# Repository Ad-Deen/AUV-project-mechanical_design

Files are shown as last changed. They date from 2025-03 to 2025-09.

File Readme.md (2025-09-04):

# AUV Mechanical Design - Evolution & Strategy

## Overview
This repository documents the mechanical design considerations and evolution of our Autonomous Underwater Vehicle (AUV) Project - Orca. The primary focus is on achieving optimal buoyancy, stability, and structural integrity while ensuring efficiency in underwater maneuverability.



## **Version 1: Initial Design & Challenges**

### **Design Approach:**
- The **center of mass** was initially intended to be at the geometric center of the bot.
- An **aluminum frame** was used to hold the hull, providing structural support.
- The frame was **hollow**, which contributed to **positive buoyancy**.

### **Manufactured results:**

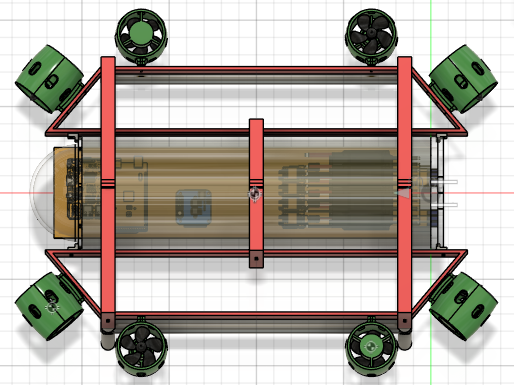
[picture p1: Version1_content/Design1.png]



### **Challenges Faced:**
- The **center of mass** shifted backward, affecting stability.
- The **bot became overly buoyant**, requiring **up to 15 kg** of additional external weight to counteract the buoyancy.
- Excessive weight led to:
  - **High inertia**, making rapid underwater maneuvers difficult.
  - **Increased battery consumption** due to the excessive mass to be controlled.
- The overall design proved inefficient in terms of weight distribution and control underwater.

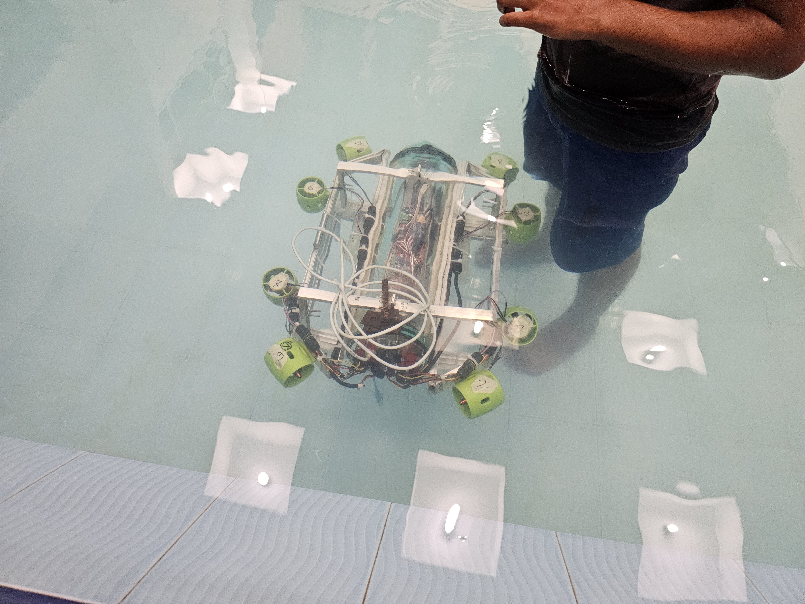
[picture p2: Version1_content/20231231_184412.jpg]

- The natural bouyancy control mechanism was also made but not utilized for core design issues
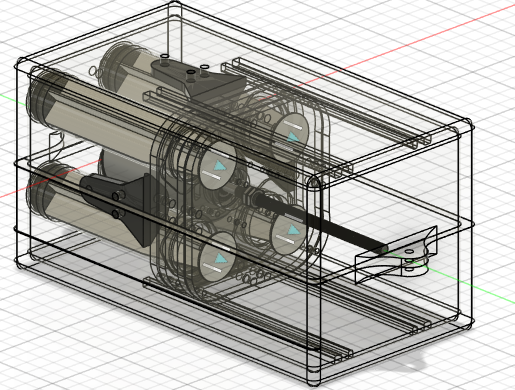
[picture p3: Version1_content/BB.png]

-The Buoyancy control mechanism in action 



## **Version 2: Optimized Design & Improvements**
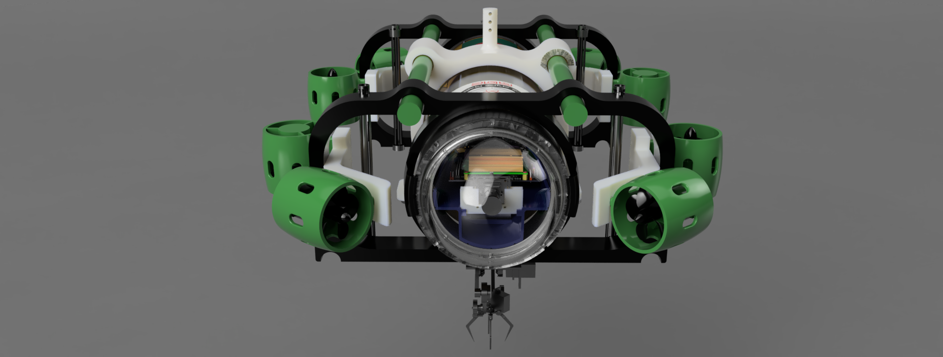
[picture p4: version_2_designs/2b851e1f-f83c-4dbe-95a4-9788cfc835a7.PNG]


### **Design Modifications:**
- The frame was **redesigned and 3D printed** with **100% infill density wiht PETG** to achieve a **negatively buoyant** structure.
- External volume was **minimized**, reducing drag and making the design more compact.
- The updated frame, in combination with:
  - The **weight of electronics**
  - **External weight holders**
  ensured the bot achieved **neutral buoyancy at 9 kg**, without requiring additional weights.
- Slots were still included in the design for **optional weight adjustments**, providing flexibility.

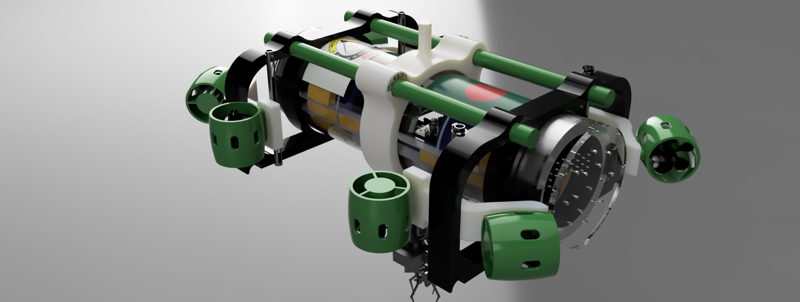
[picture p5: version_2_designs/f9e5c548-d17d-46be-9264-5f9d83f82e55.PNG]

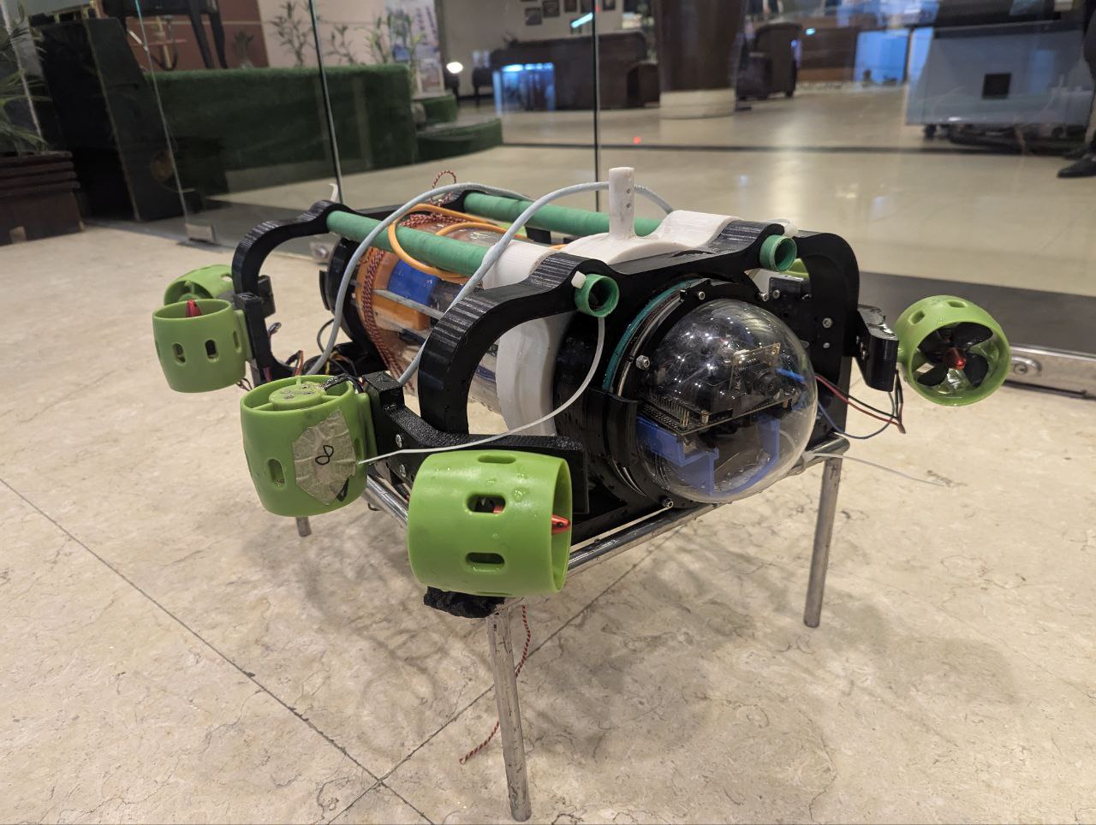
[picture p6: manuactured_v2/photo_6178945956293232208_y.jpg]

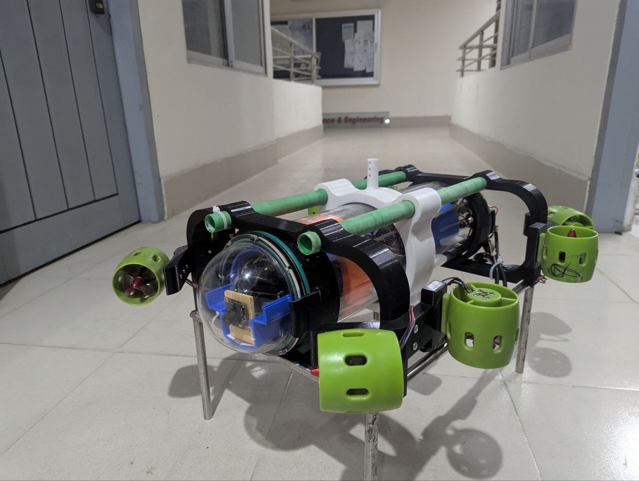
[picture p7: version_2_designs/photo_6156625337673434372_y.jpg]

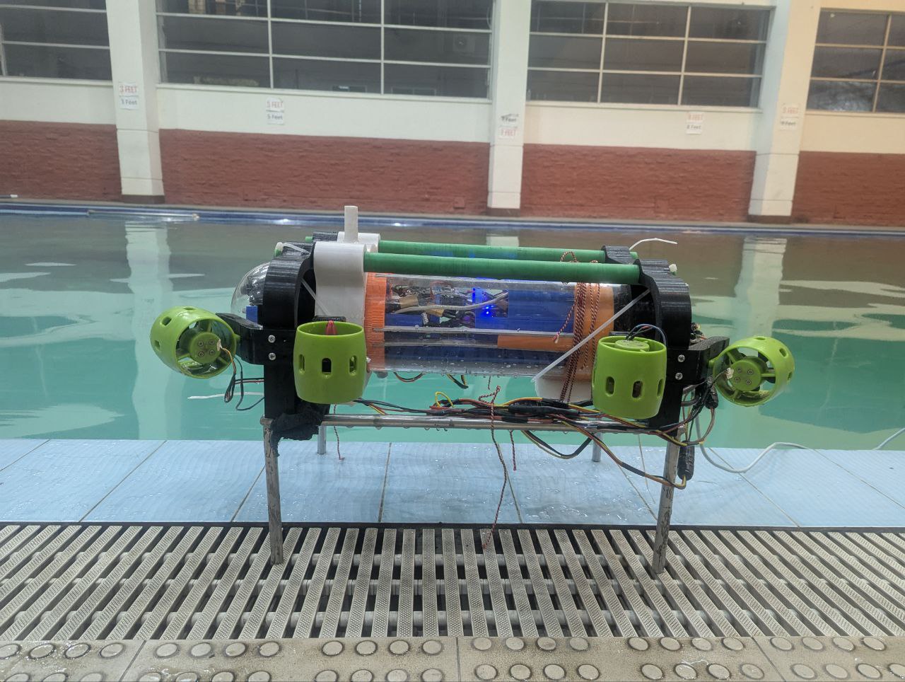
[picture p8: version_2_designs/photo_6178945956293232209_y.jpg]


### **Centre of Gravity adjustment system:**
- **The x axis is th principal axis for the robot's orientation** and we can adjust centre of gravity distribution along the principal axis for **robust passive adjustment** of it's centre of gravity alighment.
- The design was done in such a way that the center of gravity must lie along the central **x-axis**.
- While **variable adjustment of CoG along x axis** means we can accurately maintain a steady Centre of gravity position at **pitch close to 0 degree**.
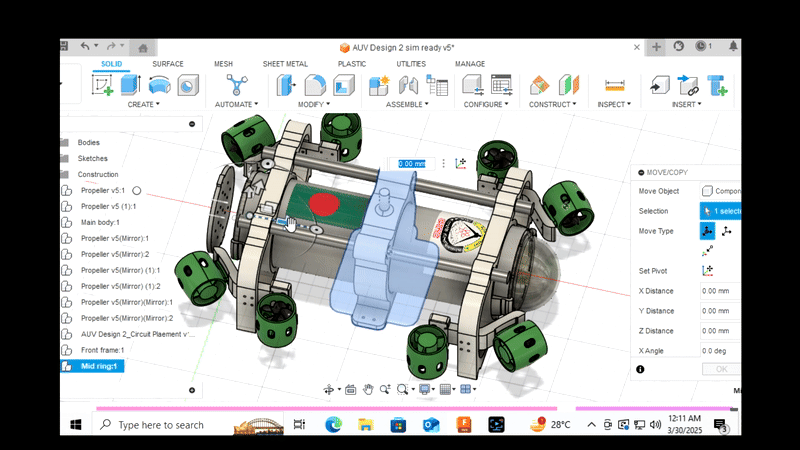
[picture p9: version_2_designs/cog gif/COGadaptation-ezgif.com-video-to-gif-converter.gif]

- Here is the working version of the same mechanism on our AUV


### **Internal Design for Electronics assembly:**
- Hull internal chamber is designed to accomodate the power and logic circuit with esc controllers and micro controllers.
- The 3D prints are done with PETG+ 100% infill density.
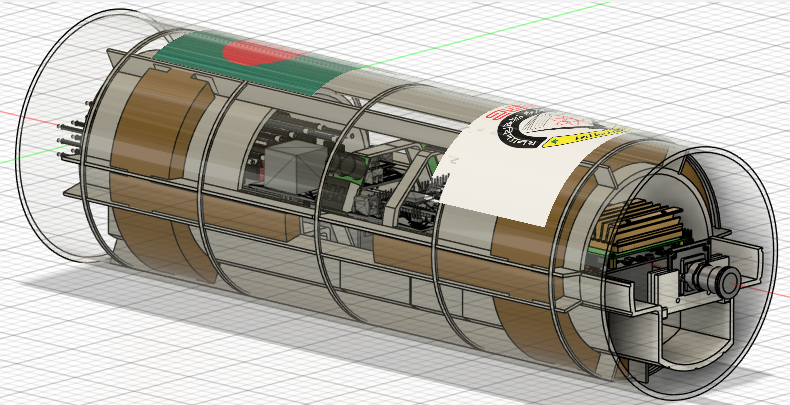
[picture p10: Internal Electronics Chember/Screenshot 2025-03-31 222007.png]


<div style="white-space: nowrap;">
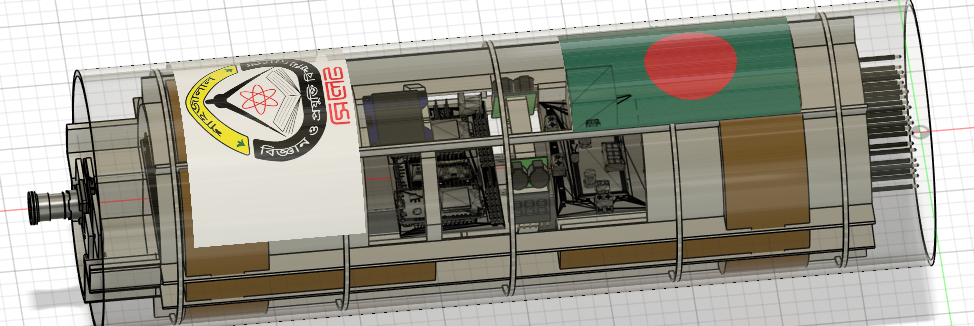
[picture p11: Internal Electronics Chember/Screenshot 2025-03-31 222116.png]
  
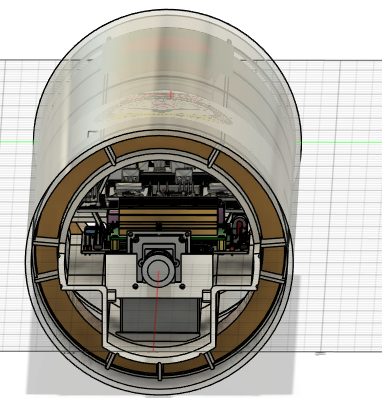
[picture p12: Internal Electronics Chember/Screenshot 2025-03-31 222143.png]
  
</div>
- The internal design section placed with electronics after the manufacturing and printing the Designs

   

### **Custom 6 DOF manipulator Design:**
- One of the **primary task** was to **pick up a 3cm radius ball** from a busket underwater.
- So we designed a robotic manipulator for it. The **launch pad consist of a camera**. The base (the launching pad) has a **radial targeting system with 2 underwater servo for Azimuth and Elevation adjustment**.
- Another servo to **launch the gripper to the target**. ANother **string based controlled gripper** with a mini servo to grip the target.
- This ensures smooth targeting and launching of the End Effector towards the target calculating underwater proximity using the camera.
- The **bavel gear system allowed opposite rotary mechanism** to launch the EF to the target with accurate mechanism **avoiding the need for and addition servo for two extension rods holding the EF**.
  
<div style="white-space: nowrap;">
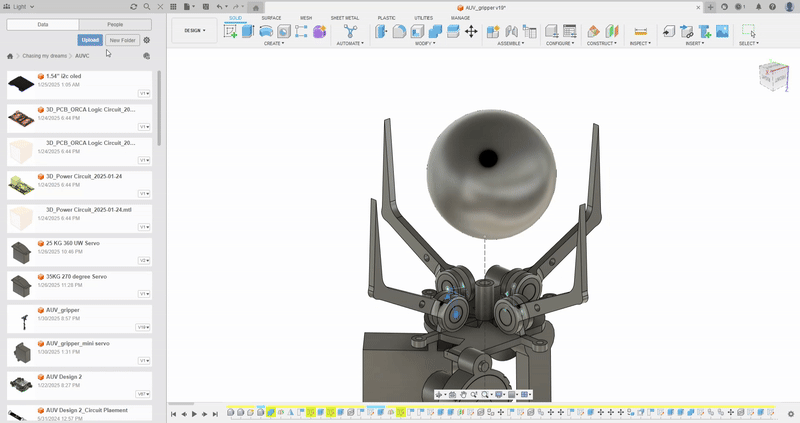
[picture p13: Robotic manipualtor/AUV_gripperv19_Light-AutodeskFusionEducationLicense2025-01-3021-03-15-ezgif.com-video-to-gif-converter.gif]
  
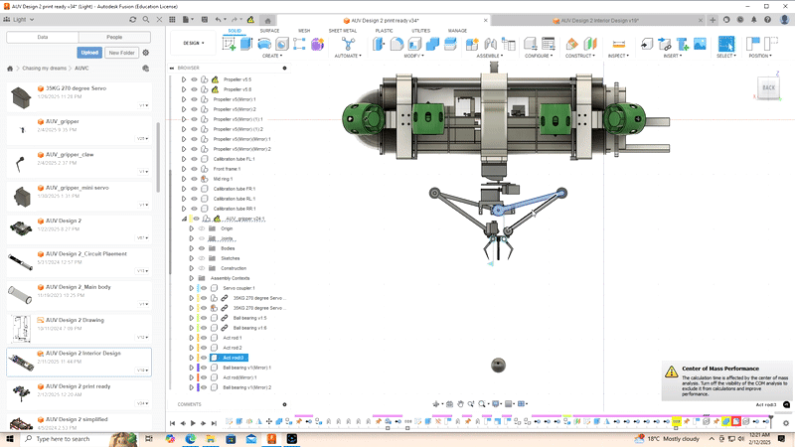
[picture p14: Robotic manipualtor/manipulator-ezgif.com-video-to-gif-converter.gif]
  
</div>

### **Summary of Components Used for Mechanical Development:**
- We used the following components listed below in the table:
 
| Component Name | Description | Quantity | Supplier / Source |
|---|---|---|---|
| [Main Hull & Caps](https://grabcad.com/library/project-orca-auv-1) | The Acryllic cylindar caging all electronics| 1 | [Blue Robotics](https://bluerobotics.com/product-category/watertight-enclosures/locking-series/) |
| [BLDC Propellers](https://grabcad.com/library/project-orca-auv-1) |Thrusters for Actuation| 8 | [RoboticsBD](https://store.roboticsbd.com/underwater-robotics/1372-underwater-thruster-brushless-motor-4-blade-propeller-propulsion-30-200w-pair-robotics-bangladesh.html) |
| Beat LiPo Battery 4S | Main power Source| 2(parallel) | [Local online sources](https://radiogearbd.com/) |
| [FrameV1(Holds the propellers with hull)](https://d2t1xqejof9utc.cloudfront.net/screenshots/pics/df02c0b4d97d6d60ab800cae76a2f348/original.png) | Custom printed with Fusion360  | 5 parts | [Printer](https://robohub.com.bd/printing-products)
| [FrameV2(Holds the propellers with hull)](https://d2t1xqejof9utc.cloudfront.net/screenshots/pics/305221f855414a7adf2119a9c982b4c0/original.png) | Custom printed with Fusion360  | 6 parts | [Printer](https://robohub.com.bd/printing-products)|
| [FrameV3(Holds the propellers with hull)](https://d2t1xqejof9utc.cloudfront.net/screenshots/pics/5d900b18f20a09c7b10679acbfe8f5c5/original.png) | Custom printed with Fusion360  | 9 parts | [Printer](https://robohub.com.bd/printing-products)|
| Killswitch Rotary | Emergency Shutdown | 1 |[Blue Robotics](https://bluerobotics.com/product-category/watertight-enclosures/locking-series/) |
| [Robotic Manipulator Arm(Custom Made)](https://d2t1xqejof9utc.cloudfront.net/screenshots/pics/e86ad652f1174167f072f850d9c034c4/original.png) | Fetching obstacles underwater(3cubic-cm volume) | 13 parts |[Printer](https://robohub.com.bd/printing-products)|
| [Buoyancy Box(custom made](https://d2t1xqejof9utc.cloudfront.net/screenshots/pics/9e2de9b92106f65e2a5b7596a32450cb/original.png) | Designed to control dive depth using Buoyancy | 8 parts | [Printer](https://robohub.com.bd/printing-products) |

### **Outcome & Benefits:**
- The bot achieved **better buoyancy balance**.
- **Improved energy efficiency**, as less power was required to stabilize and move.
- **Enhanced maneuverability**, allowing smoother and quicker control underwater.
- A structurally **more robust and modular design** suitable for further optimizations.
- **Detailed contents on Version 2 designs**
[Access Folder on Google Drive](https://drive.google.com/drive/folders/1BLFM8DaaLz3syUbcvgXGc0M6o55n4rce?usp=drive_link)

### **Contribution to AUV Community:**
- We are **open sourcing our design** parts so that any one may find our design useful and use it for their own projects and research for further advancement of AUV technology.
- Anyone interested might find our design parts in the GrabCAD community [here](https://grabcad.com/library/project-orca-auv-1).
- Fusion Design files are [**here**](https://drive.google.com/drive/folders/1AVeISJ2-F0yfOsdWyq161qzJSzpWZmEW?usp=sharing) 

## **Conclusion**
Through iterative mechanical design, we successfully transitioned from an overweight, difficult-to-control AUV to a compact, efficient, and neutrally buoyant design. These insights will guide further refinements in our pursuit of a high-performance underwater vehicle.

---

For further queries, feel free to raise an issue or contribute to the repository!

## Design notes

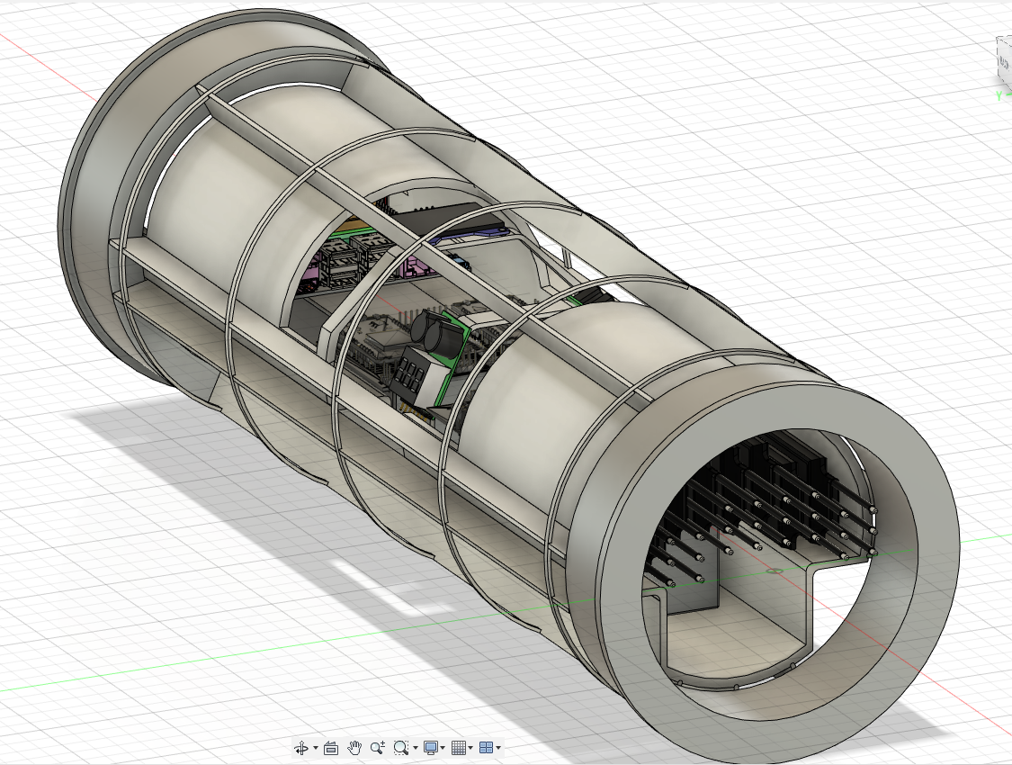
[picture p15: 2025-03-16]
version_2_designs/Screenshot 2025-01-25 115550.png

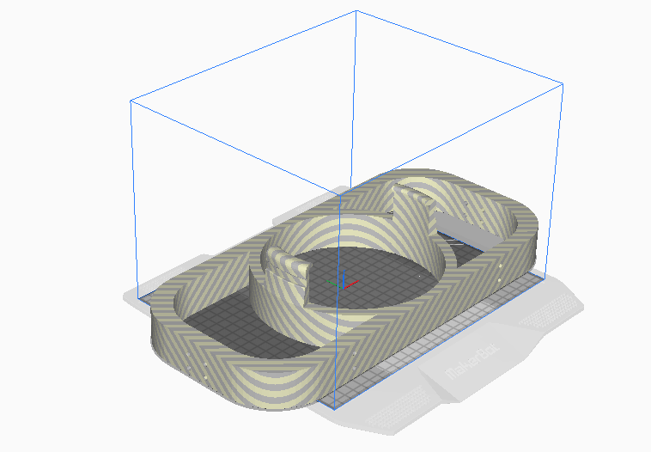
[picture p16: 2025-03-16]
version_2_designs/470057928_1773486700111839_3875716919222527097_n.png

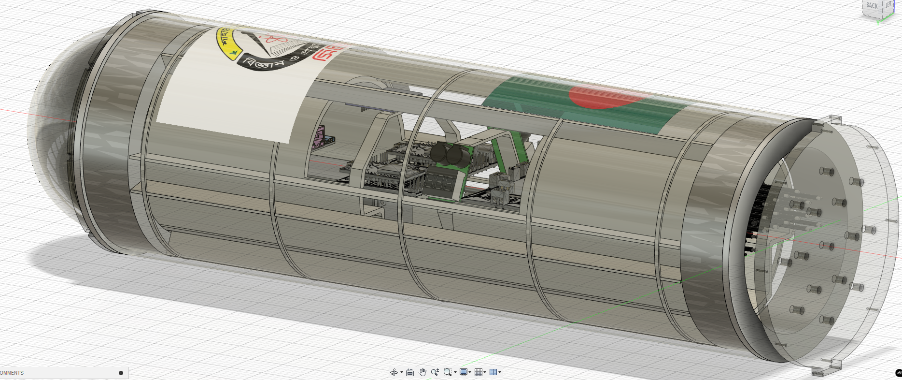
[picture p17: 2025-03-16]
version_2_designs/Screenshot 2025-01-25 115731.png

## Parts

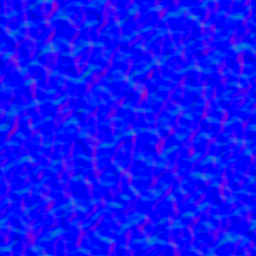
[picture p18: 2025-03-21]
ORCA frame 3D PRINT/Updated parts/acb73426-d4a8-4911-9e1f-91d1d6210688/3/1506733824938393100_normal.png

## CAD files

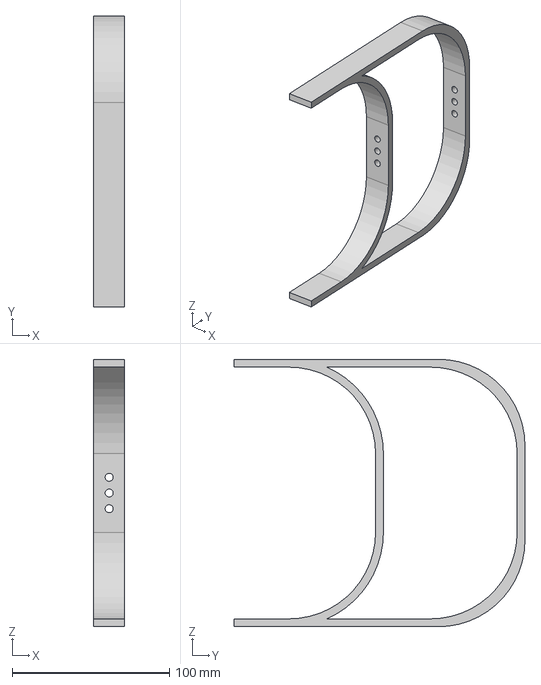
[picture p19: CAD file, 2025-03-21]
ORCA frame 3D PRINT/Clamp left(Mirror).step
20.0 x 185.0 x 170.0 mm

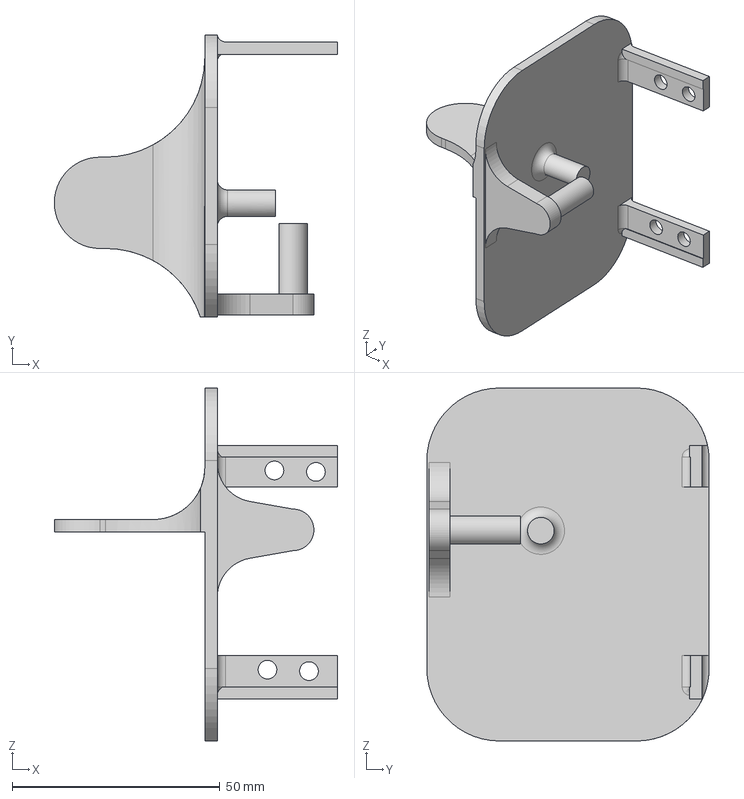
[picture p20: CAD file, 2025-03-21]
ORCA frame 3D PRINT/Manipulator parts/Base2.0/Base2.step
68.2 x 68.0 x 85.0 mm

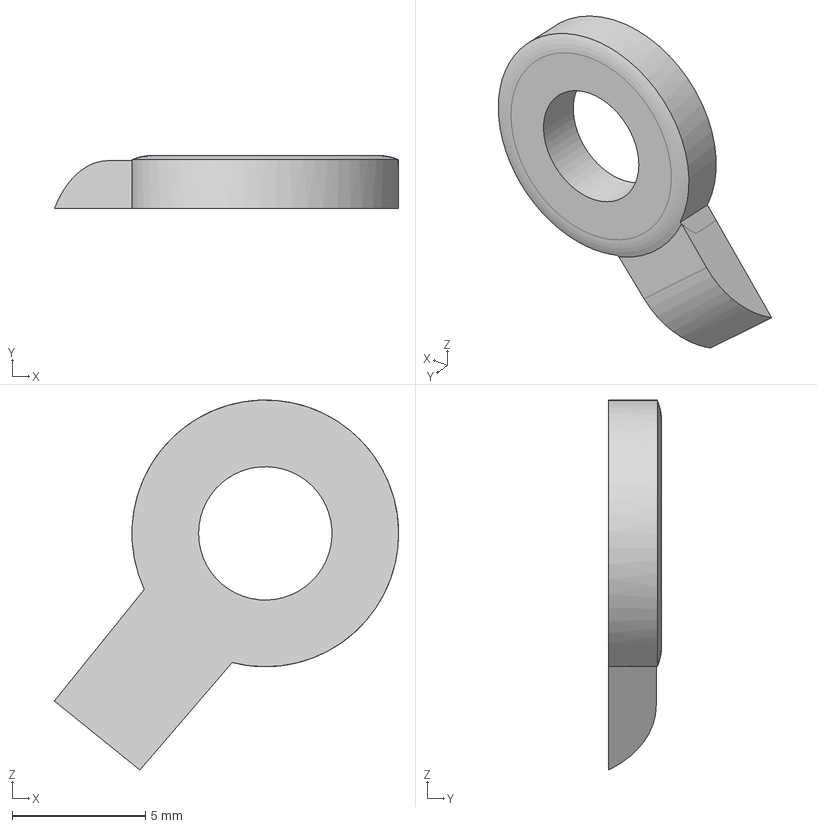
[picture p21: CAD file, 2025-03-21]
ORCA frame 3D PRINT/Manipulator parts/claw/claw1.step
12.9 x 2.00 x 13.9 mm

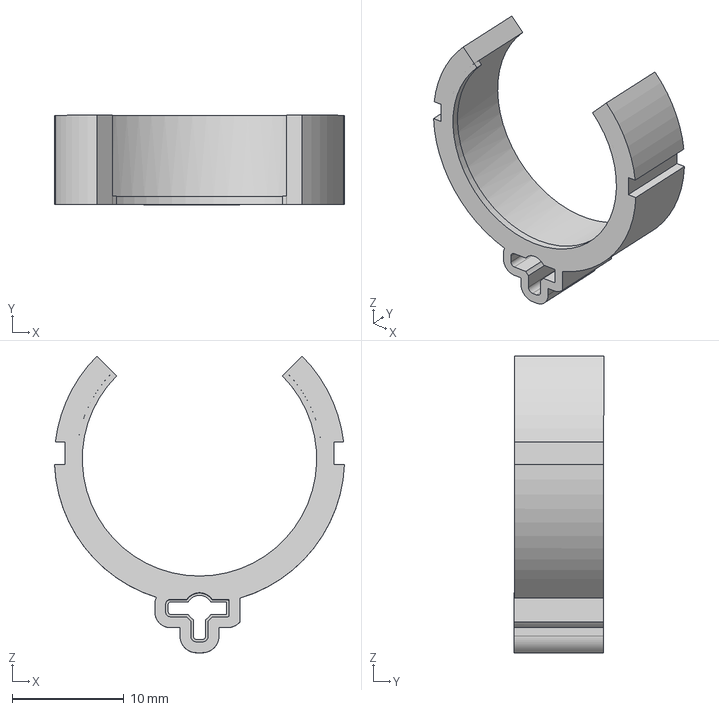
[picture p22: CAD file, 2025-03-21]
ORCA frame 3D PRINT/Manipulator parts/end effector/base/bearing socket.step
26.0 x 8.03 x 26.6 mm

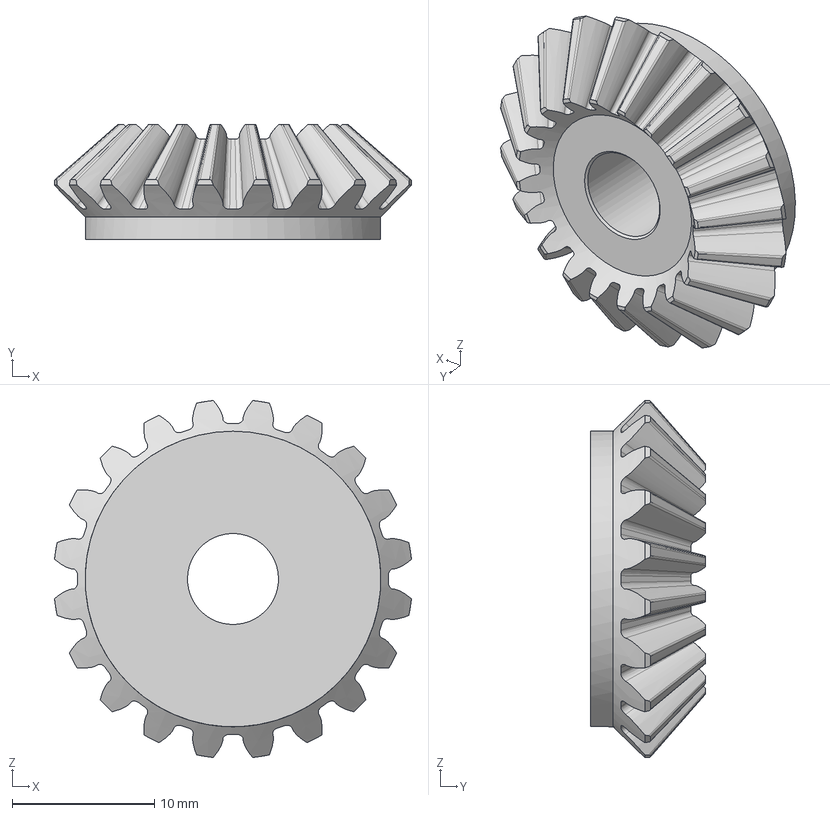
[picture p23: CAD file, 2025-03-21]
ORCA frame 3D PRINT/Manipulator parts/rods/AUV_gripper_Bavel gear v1 v1.step
25.1 x 8.12 x 25.1 mm

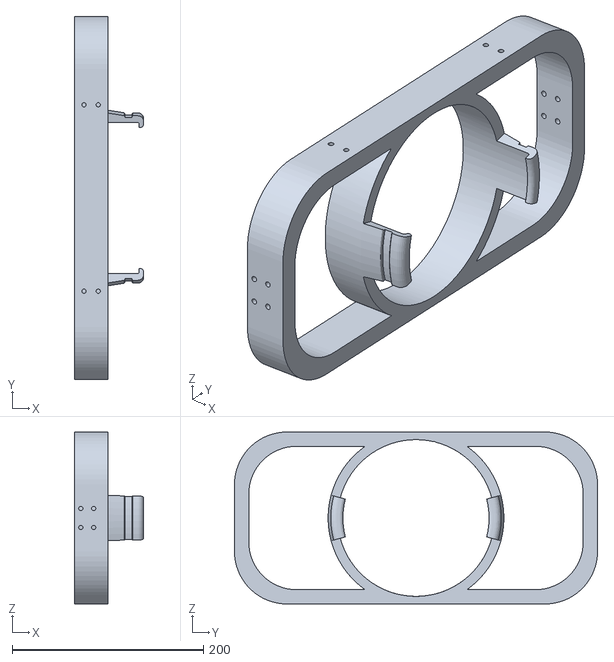
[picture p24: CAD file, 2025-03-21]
ORCA frame 3D PRINT/Updated parts/Body5.stl
72.5 x 380.0 x 180.0

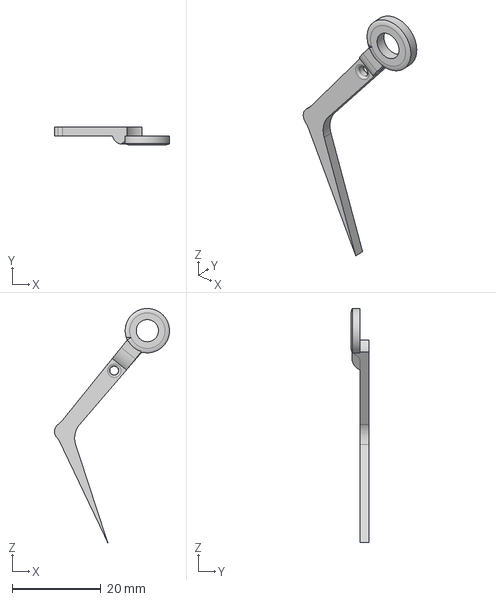
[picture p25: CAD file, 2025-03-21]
ORCA frame 3D PRINT/Manipulator parts/claw/claw2.step
25.9 x 4.00 x 52.7 mm

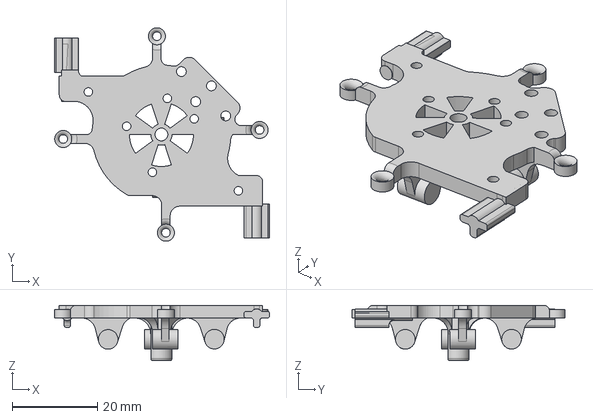
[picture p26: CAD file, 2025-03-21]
ORCA frame 3D PRINT/Manipulator parts/end effector/base/Base1.step
50.4 x 50.0 x 13.0 mm

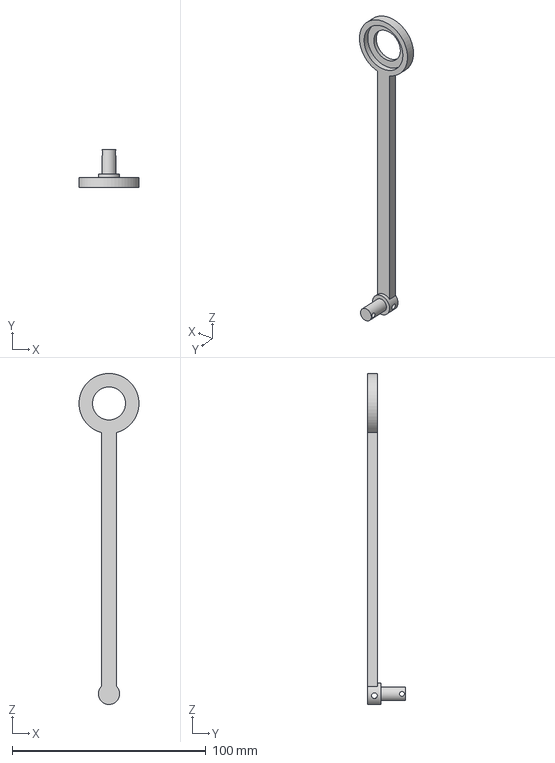
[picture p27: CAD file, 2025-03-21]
ORCA frame 3D PRINT/Manipulator parts/rods/rod.step
31.0 x 19.5 x 171.0 mm

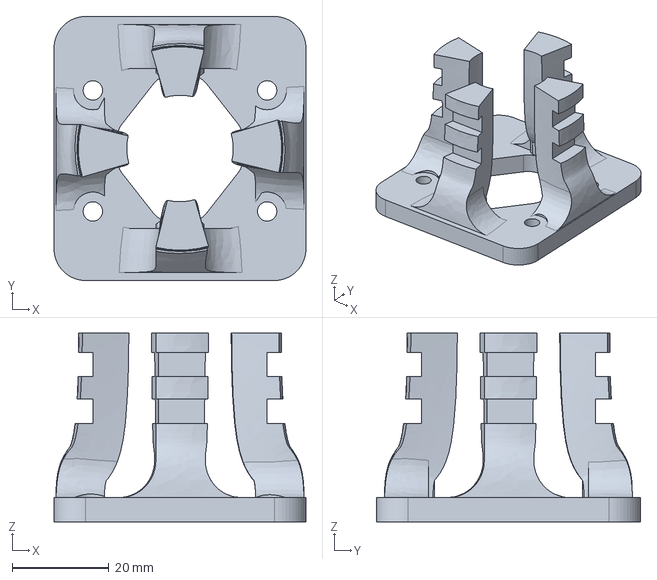
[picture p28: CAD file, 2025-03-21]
ORCA frame 3D PRINT/Rotor holder.step
52.0 x 54.5 x 39.0 mm

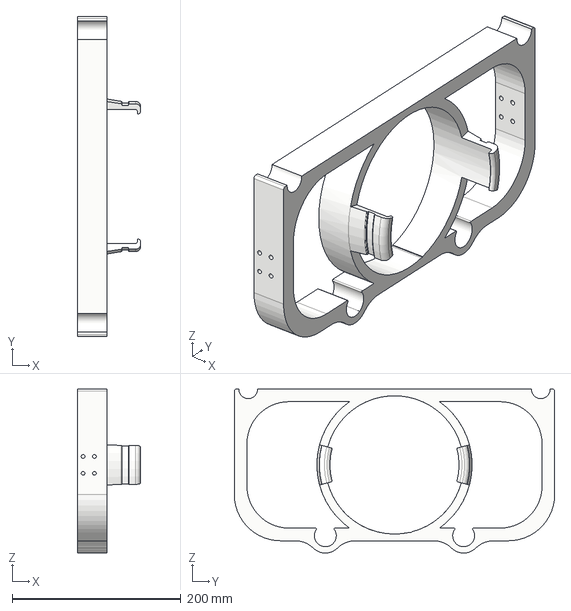
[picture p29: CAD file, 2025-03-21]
ORCA frame 3D PRINT/Updated parts/Back_frame.step
75.0 x 380.0 x 194.5 mm

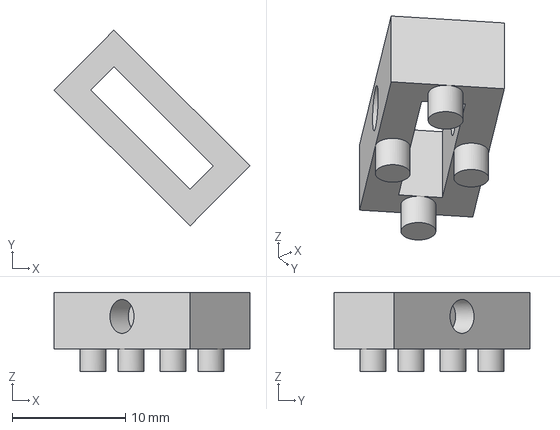
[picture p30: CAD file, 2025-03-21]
ORCA frame 3D PRINT/Manipulator parts/end effector/base/servo socket.step
17.3 x 17.3 x 7.00 mm

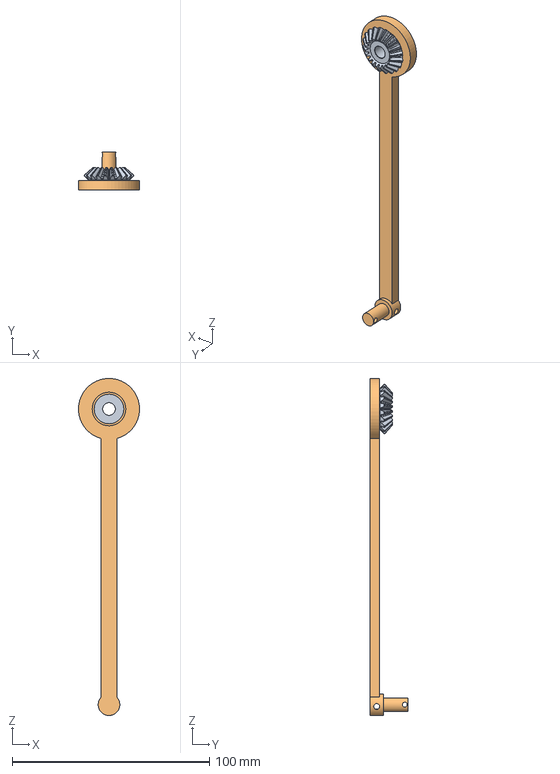
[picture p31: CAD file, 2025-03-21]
ORCA frame 3D PRINT/Manipulator parts/rods/rod with bavel.step
31.0 x 19.5 x 171.0 mm

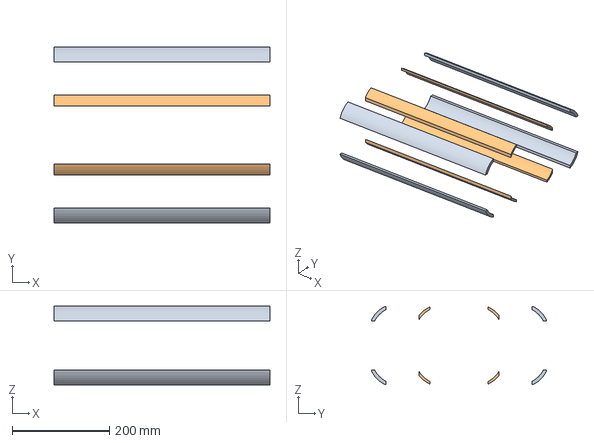
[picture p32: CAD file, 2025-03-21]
ORCA frame 3D PRINT/Support frames.step
445.0 x 362.5 x 162.5 mm

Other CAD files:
ORCA frame 3D PRINT/Clamp left.step
ORCA frame 3D PRINT/Left frame(Mirror).step
ORCA frame 3D PRINT/Left frame.step
ORCA frame 3D PRINT/Clamp left(Mirror)(Mirror).step
ORCA frame 3D PRINT/Clamp left(Mirror) (1).step
ORCA frame 3D PRINT/Updated parts/back frame.step
